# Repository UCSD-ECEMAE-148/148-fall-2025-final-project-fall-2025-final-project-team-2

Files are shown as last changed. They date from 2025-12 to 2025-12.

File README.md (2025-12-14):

<h1 align="center">Autonomous FireFighting Robot</h1>
<h3 align="center">ROS 2–Based Perception, Decision-Making, and Fire Suppression</h3>
<h4 align="center">Final Robotics Project</h4>

<br>

<div align="center">
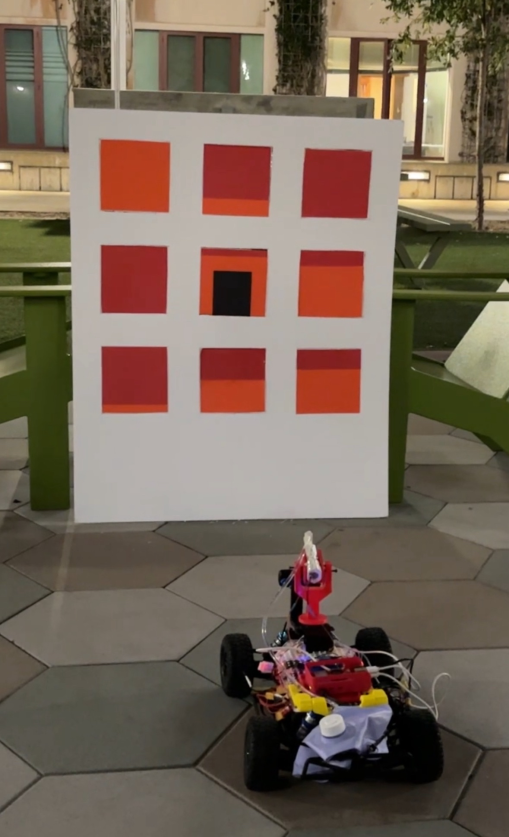
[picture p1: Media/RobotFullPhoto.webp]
  
</div>

<br>

<div align="center">
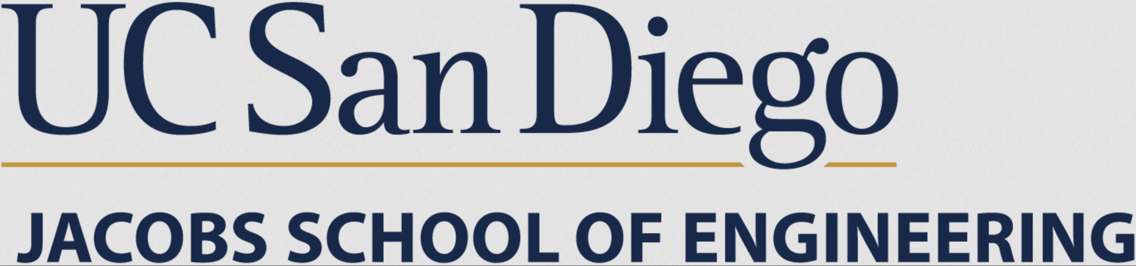
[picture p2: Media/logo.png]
  
</div>

## Table of Contents
<ol>
  <li><a href="#team-members">Team Members</a></li>
  <li><a href="#abstract">Abstract</a></li>
  <li><a href="#what-we-promised">What We Promised</a></li>
  <li><a href="#accomplishments">Accomplishments</a></li>
  <li><a href="#challenges">Challenges</a></li>
  <li><a href="#final-project-videos">Final Project Videos</a></li>
  <li><a href="#software">Software</a></li>
  <ul>
    <li><a href="#overall-architecture">Overall Architecture</a></li>
    <li><a href="#fire-perception">Fire Perception</a></li>
    <li><a href="#decision-making--task-planning">Decision-Making & Task Planning</a></li>
    <li><a href="#turret-aiming--water-cannon-control">Turret Aiming & Water Cannon Control</a></li>
    <li><a href="#navigation--localization-optional">Navigation & Localization (Optional)</a></li>
  </ul>
  <li><a href="#hardware">Hardware</a></li>
  <li><a href="#gantt-chart">Gantt Chart</a></li>
  <li><a href="#course-deliverables">Course Deliverables</a></li>
  <li><a href="#project-reproduction">Project Reproduction</a></li>
  <li><a href="#acknowledgements">Acknowledgements</a></li>
  <li><a href="#contacts">Contacts</a></li>
</ol>
<hr>

## Team Members

- **Natan Beneviste** — Mechanical Engineering
- **Vivan Tran** — Computer Engineering
- **Tanguy His** — Robotics Engineering
- **Shanil Patel** — Aerospace Enigineering

<hr>

## Abstract

The goal of this project is to develop an autonomous firefighting robot capable of detecting the locations of window fires on a mock building, estimating the severity of each fire, using a cost based algorithm to decide an optimal sequence to extinguish them efficiently, and then manipulate a relay controlled water cannon to eliminate each  window fire sequentially. 

The robot utilizes ROS2 as its foundational architecture with an OAK-D Lite camera for perception. Fire intensity is estimated from image frames using a color-based scale, more red pixels means a fire with a higher temperature and more orange pixels means a cooler fire. If a black square is present it means a person is stuck at that window location. The output of this function produces a matrix of window index, fire intensity, and person boolean (one  per window) as well as a graph for visualization. A decision-making node inputs these values into a cost based algorithm which outputs the highest value window, meaning the window that must be extinguished first. We based this algorithm on how real firefighters prioritize locations for extinguishing building fires. Finally, a turret-control node aims a servo-actuated water cannon to adjust x-axis position and the drivetrain moves to adjust y-position to aim toward the selected window in real time.  

<hr>

## What We Promised

- Detect “fire” regions (red-painted metal pieces) on a cardboard building using the OAK-D Lite camera.
- Estimate a fire intensity for each window.
- Publish a structured list of targets to ROS2.
- Compute the next best target using a custom score function.
- Aim a single-servo turret and acutated the drivetrain toward the selected window and trigger suppression.

<hr>

## Accomplishments
- **Fire Perception Node**
  - Implemented ROI-based window extraction.
  - Implemented red-orange-intensity estimation.
  - Can detect the presence of a person ( based on a non red/orange color that's in the window).
  - Published a fire-node list containing window IDs, temperatures, and neighbor influence values.
- **Decision-Making Node**
  - Implemented graph-based target representation.
  - Implemented next-target selection using a custom score formulation (distance + intensity + neighbor effects + presence of a person at the window).
- **Turret Control Node**
  - Implemented camera-based aiming for a 1-DOF turret.
  - Implemented drivetrain control for y-position movement  
  - Implemented servo PWM output with limits.

<hr>

## Challenges

- **Robust perception under lighting variation**
  - Red detection is sensitive to illumination;
- **System integration**
  - Ensuring consistent message timing and stable TF/frame assumptions across nodes.
  - Having the Brain Node sequentially run the other nodes 
- **Power and reliability**
  - Separating high-current actuator power (pump/motors) from logic power and filtering noise are critical for stable operation.
<hr>

## Final Project Videos

Final project demonstration: https://youtube.com/shorts/yiU66X_UAJ0
<hr>

## Software

### Overall Architecture

This project was developed in ROS2 using a modular pipeline that cleanly separates perception, decision-making, and hardware. Each stage runs as an independent ROS2 node and is communicated exclusively through topics allowing the system to be sequential.

The system will execute and repeat this sequence:

see → decide → servo → drivetrain → fire

---

## ROS 2 Node-Level Architecture

<div align="center">
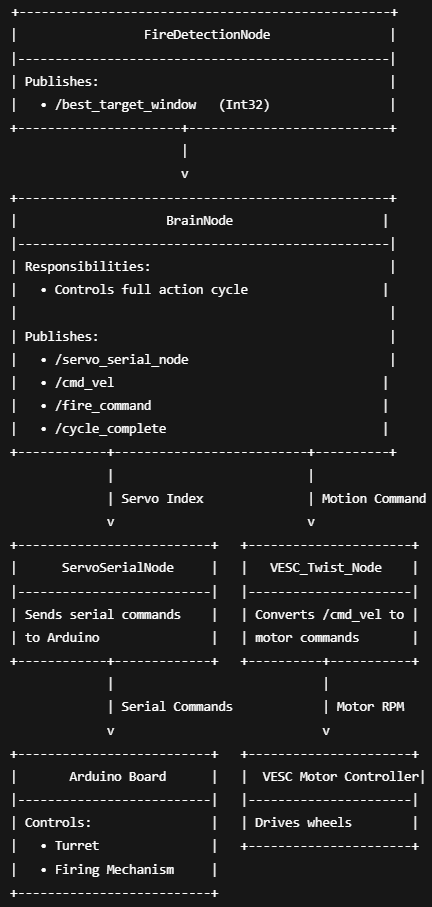
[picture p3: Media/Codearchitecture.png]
  
</div>

---

### HSV Window Labeling
<div align="center">
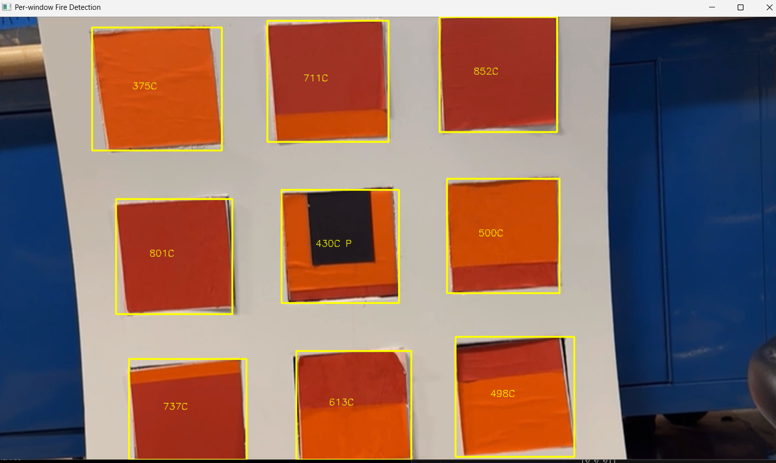
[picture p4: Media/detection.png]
  
</div>
Heat is determined through the amount of red and orange pixels. More red indicates hotter temperate and more orange indicates cooler temperatures. There is a black box that will show there is a person present in the window. The mock building made of cardboard will have these variables present and the HSV Window Labeling will output those live variables to a matrix with window id, fire intensity, neighbors fire intensity, person present boolean.

---

**ROI-based window extraction**

- A calibration step defines fixed window bounding boxes (ROIs).
- Each incoming frame is cropped into per-window patches.
- Each patch is resized and normalized.

---

**Intensity estimation**

**Baseline (color-based):**

- Convert ROI to HSV or La for improved robustness to lighting changes.
- Compute a red/orange intensity score based on hue and saturation thresholds.
- Map this score to a normalized temperature or fire intensity index.

---

**Output message**

The HSV Window Labeling library publishes a structured list of detected fire windows:

- window ID – lists windows in matrix order
- temperature / intensity – determined through the amount of orange and red (outputted as a 3x3 matrix correlated with the window ID)
- Boolean Person matrix – 3x3 matrix, 1 indicated that there is a person, 0 otherwise

---

### Decision-Making & Task Planning

The decision-making library will input the matrix form the HSW Window Labeling, applying the formula (indicated below) and then outputting the window with the highest cost, needing to be extinguished first. 

At each iteration, the function selects the next window to extinguish by minimizing a custom cost:

- balance between:
  - travel cost (distance/time),
  - fire urgency (temperature),
  - cluster effects (neighbor influence),
  - predicted growth over time,
  - presence or not of a person

This is the equation:

cost = w1 · travel_cost
     + w2 · fire_intensity
     + w3 · neighbor_influence
     + w4 · predicted_growth
     + w5 · safety_penalty

---

### Fire_Dection_Node

The Fire Detection Node is responsible for converting raw camera images into a structured, decision-ready representation of the fire activity across the building. It serves as the interface between perception and decision-making, encapsulating fire detection, temperature estimation, reasoning, and debugging visualization.

This node performs three tightly integrated functions:

- Camera Input Processing
- HSV window labeling & Temperature Estimation
- Target Selection & Debug Matrix Generation

The output topics:

- Best_window → the window id of the current highest priority window
- Debug information

<div align="center">
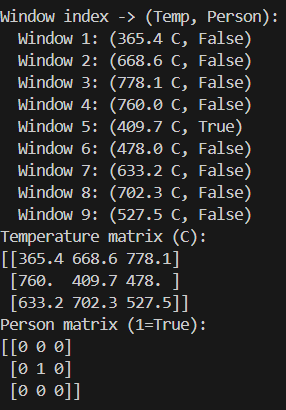
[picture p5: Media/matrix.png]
  
</div>
---

## Servo Node

Our turret has 1 servo. The camera is mounted ~5–6 cm in front of the turret base, fixed to the chassis.

### System Operation and Communication

The servo’s horizontal motion is controlled using the Arduino’s built-in **Servo library**, which sets the servo angle by outputting the appropriate **PWM signal**.

To activate the water cannon, the Arduino sends a **digital control signal** to a **relay**, which acts like an electronic switch—when triggered, it allows power to flow to the water cannon so it can fire.

The **Raspberry Pi** and **Arduino** communicate using **serial (UART) communication**. In this setup, the Raspberry Pi sends commands (such as 0–8 the windows label or “fire”) over the serial connection, and the Arduino interprets those commands and performs the real-time hardware actions (servo positioning and relay switching).

This division of roles keeps the Raspberry Pi protected from motor/relay electrical noise while allowing the Arduino to handle the precise timing needed for servo control and reliable firing.

**Summary:**

Subscribe to:
- `/fire_command` (Bool)

Interacts with:
- Arduino via `/dev/serial/...` (USB)

Sends:
- Servo angle commands (window index) to ardunio 
- FIRE command to arduino 

<hr>

### VESC Node

The **VESC node** acts as the main **motor driver interface** in our ROS2 system. It serves as the software bridge between ROS and the physical drivetrain hardware controlled by the VESC.

## Command Input (Subscribing to Motion Topics)

The best_window topic determines the target row, which requires movement either forward, backward, or idle. The VESC node listens to those motion commands published by `/cmd_vel`.

## Command Translation (ROS → VESC Control)

Once a command is received, the VESC node converts the ROS message into the low-level control signals that the VESC understands. This is what allows high-level ROS navigation or control logic to directly drive the motor without needing to handle hardware-level details.

## Feedback Output (State and Odometry Publishing)

In addition to sending commands, the VESC node publishes feedback data back into ROS such as motor speed, voltage, current draw, and/or **odometry**. This feedback helps the system confirm the drivetrain is responding correctly and track how far the robot has moved.

## Why This Matters

By separating motion commands from hardware control, the VESC node makes the drivetrain easier to control and debug. Other ROS nodes can focus on decision-making while the VESC node handles reliable motor execution and feedback. Therefore handles the forward and backward movement of the car needed for aiming the row.

### Brain Node

The Brain Node is the central decision-making and coordination node of the system. It acts as the bridge between fire perception and the hardware, ensuring that all actions occur in the correct order and without conflict.

Rather than continuously commanding hardware, the Brain Node operates as a finite state machine (FSM) that executes a single fire-suppression cycle at a time.

Its responsibilities are to:
- Receive the best_window_id
- Coordinate turret aiming, base motion, and firing system
- Signal when the cycle is complete so perception may resume

Subscribe topic:
- `/best_target_window` (Int32)

Publishes topics:
- `/servo_serial_node` (Int32)
- `/cmd_vel` (Twist)
- `/fire_command` (Bool)
- `/cycle_complete` (Bool)

---

### Internal State Machine

The Brain Node is implemented as a finite state machine to guarantee correct sequencing and prevent unsafe behavior.

**State Definitions**

- IDLE – Waiting for a valid fire target
- AIM_TURRET – Rotate turret toward target window
- MOVE_BASE – Move robot to align with target row
- FIRE – Activate water cannon
- RESET – Stop motion and unlock next cycle

---

**Execution Logic**

1. **Target Acquisition (IDLE)**  
   The Brain Node waits for `/best_target_window`.  
   Once received, it:
   - Validates the window index
   - Stores temperature and metadata
   - Locks the system to prevent new targets

2. **Turret Aiming (AIM_TURRET)**  
   - Converts the window index into a target column  
   - Publishes `/servo_serial_node` with the desired turret position  
   - Waits a fixed settling time to allow servo stabilization  
   - Prevents firing while the turret is still moving

3. **Base Alignment (MOVE_BASE)**  
   - Converts the window index into a target row  
   - Publishes `/cmd_vel` to move the robot forward or backward  
   - Uses time-based or distance-based motion control  
   - Stops motion once alignment is achieved

4. **Fire Command (FIRE)**  
   - Publishes `/fire_command = true`  
   - Holds the command long enough to ensure actuation  
   - Immediately resets `/fire_command` to false  

5. **Reset & Unlock (RESET)**  
   - Publishes `/cycle_complete = true`  
   - Clears internal state variables  
   - Returns to IDLE  

At this point, the perception node is allowed to process the next frame.

<hr>

## Hardware

**Compute**
- Raspberry Pi 5
- Arduino Leondardo Micro 
- MicroSD storage

**Sensors**
- OAK-D Lite RGB-D camera
**Actuation**
- 1x servo motor
- water pump / solenoid valve
- chassis drivetrain (VESC + motor)

**Power**
- 4S LiPo battery
- Dedicated DC-DC converters (logic 5V separated from high-current actuators)
- anti-spark voltage monitoring
  <div align="center">
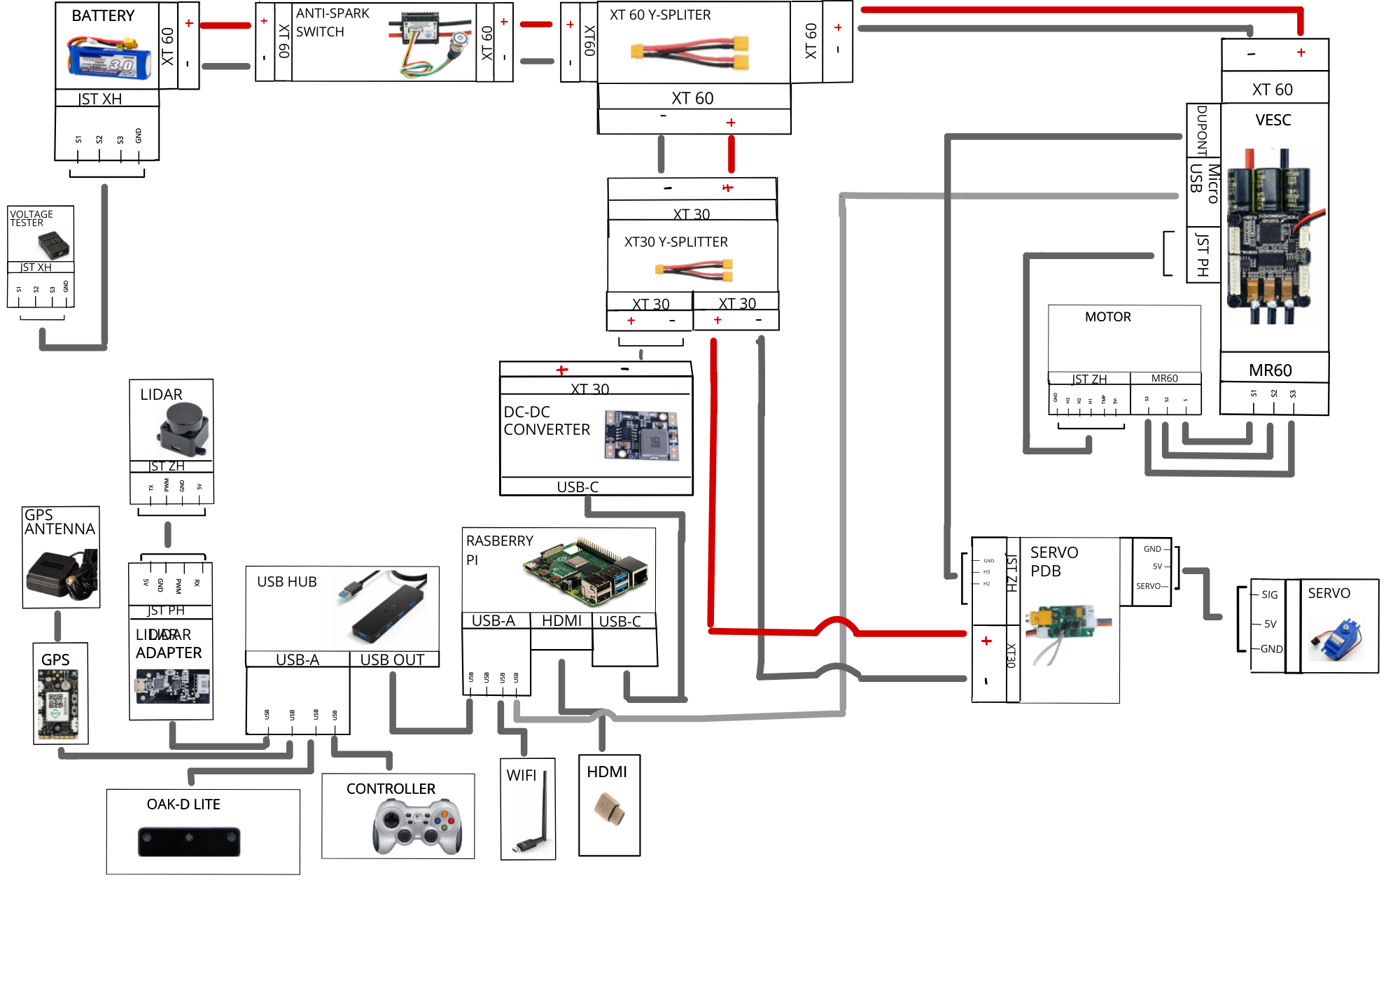
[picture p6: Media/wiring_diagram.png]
  
</div>

**Mechanical**
- Cardboard mock building with painted metal “windows”
- 3D-printed base plate
  <div align="center">
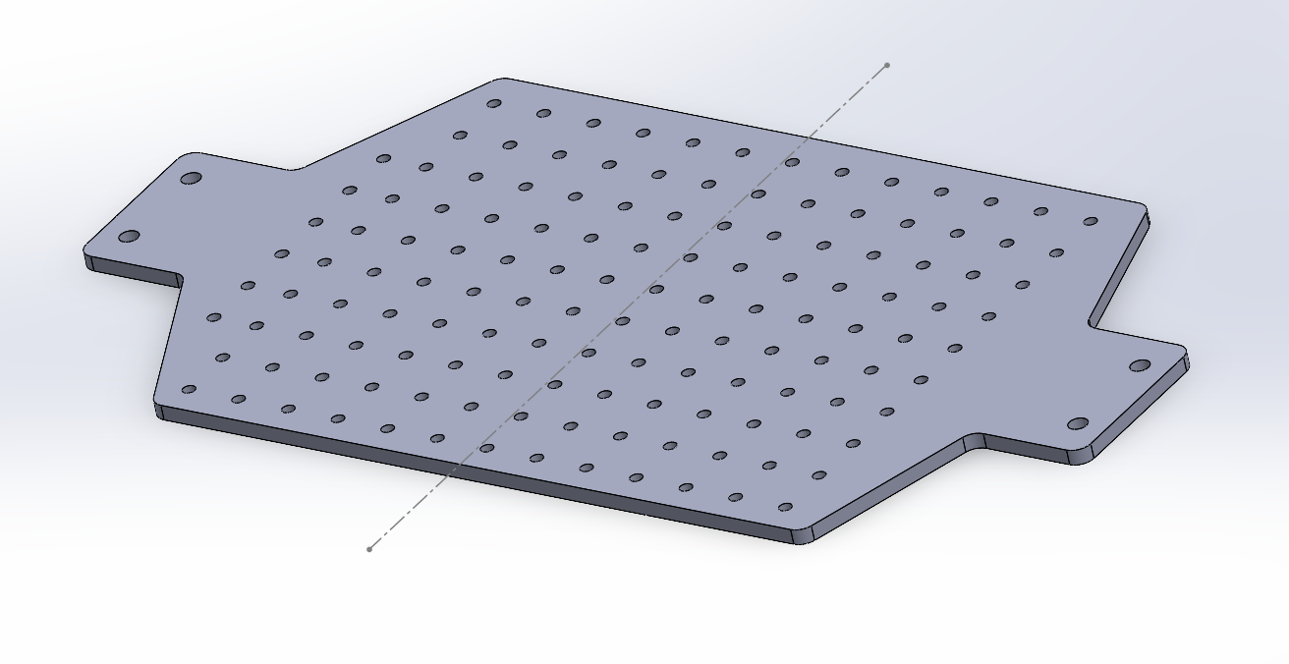
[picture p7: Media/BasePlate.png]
  
</div>
- 3D-printed mounts for camera and turret
<div align="center">
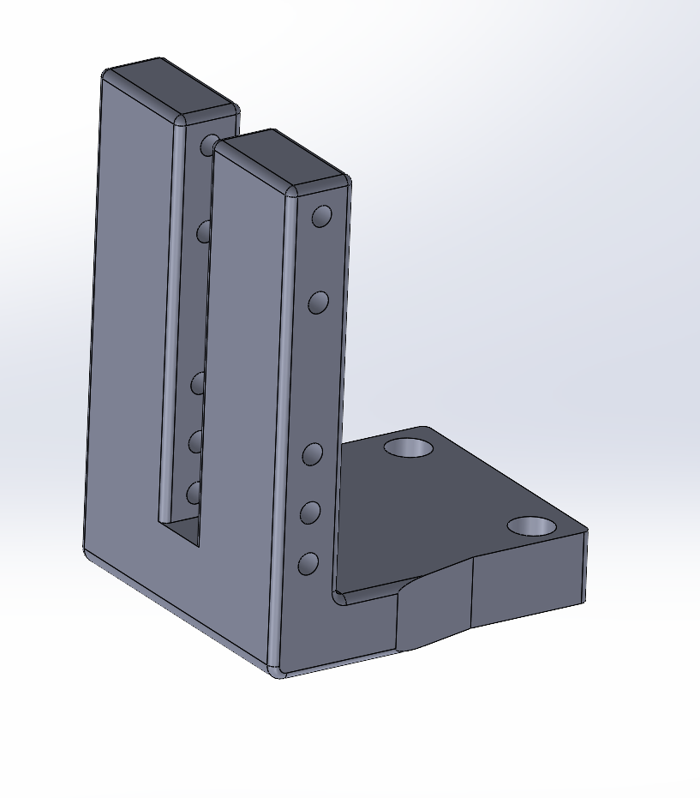
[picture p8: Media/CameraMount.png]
  
</div>
<div align="left">
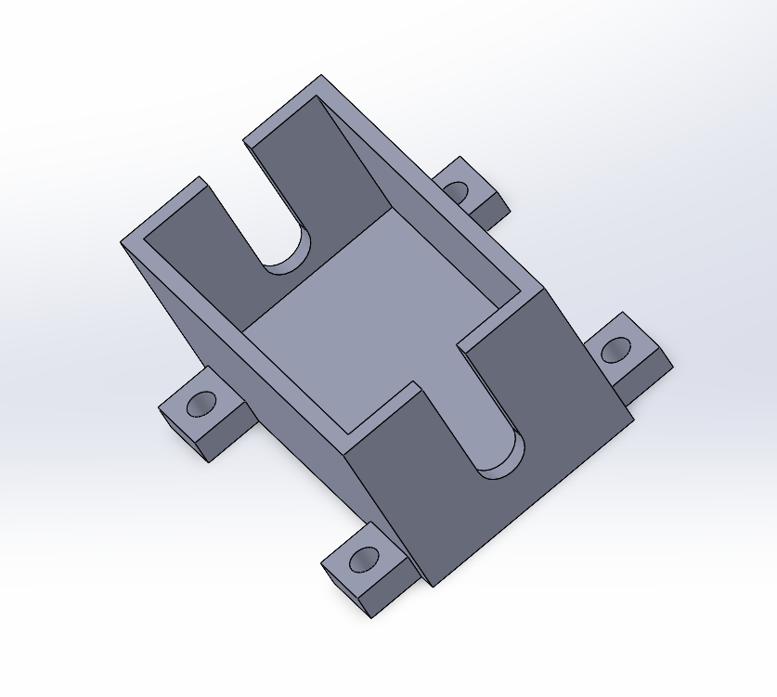
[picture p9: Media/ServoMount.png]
  
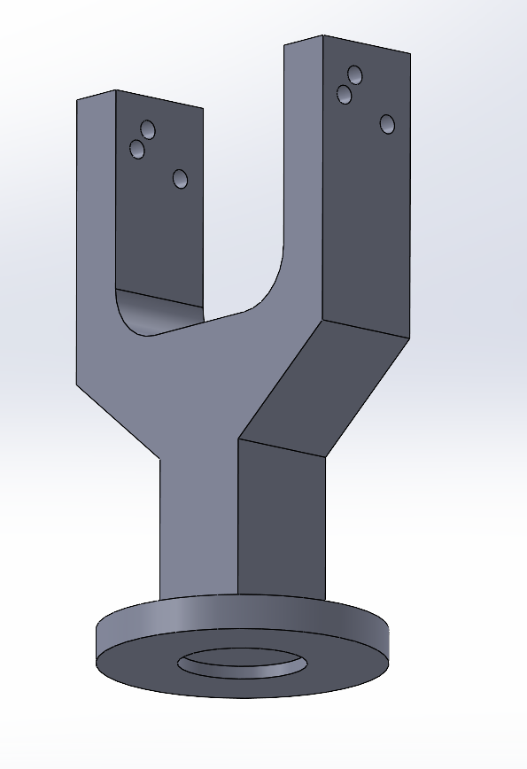
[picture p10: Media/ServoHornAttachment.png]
  
</div>
<hr>

## Water Cannon Design Choice

We chose to use a water cannon from a electronic squirt gun because it was a budget-friendly option that already included everything we needed to perform the task, such as:
- a strong pump  
- a built-in water tank  
- a compact design for easy mobility  

To protect the electronics, we kept the water tank in the trunk of the car so any leaks or spills wouldn’t risk shorting components.

## Mounting and Rotation Mechanism

We used a simple 3D-printed design to hold the water cannon securely, then the servo was mounted in a grove on the underside of the water cannon bracket to allow for it    x-position movement.

The baseplate layout was planned to leave:
- enough space on top for the servo mount  
- room for the targeting mechanism

<div align="left">
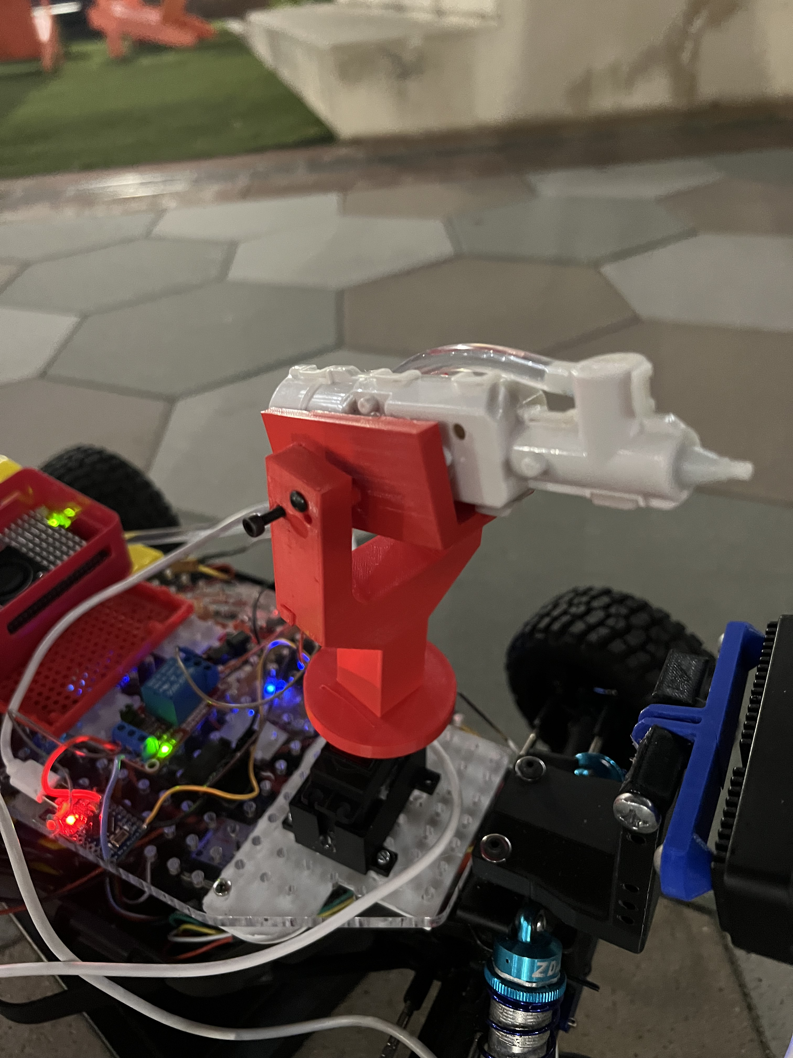
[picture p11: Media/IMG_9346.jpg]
  

## Steering Lock for Accuracy

To prevent the cannon from drifting off-target, we detached the car’s steering servo and locked it in place. This ensured there were no unintended direction changes while firing.

## Gantt Chart

 <div align="center">
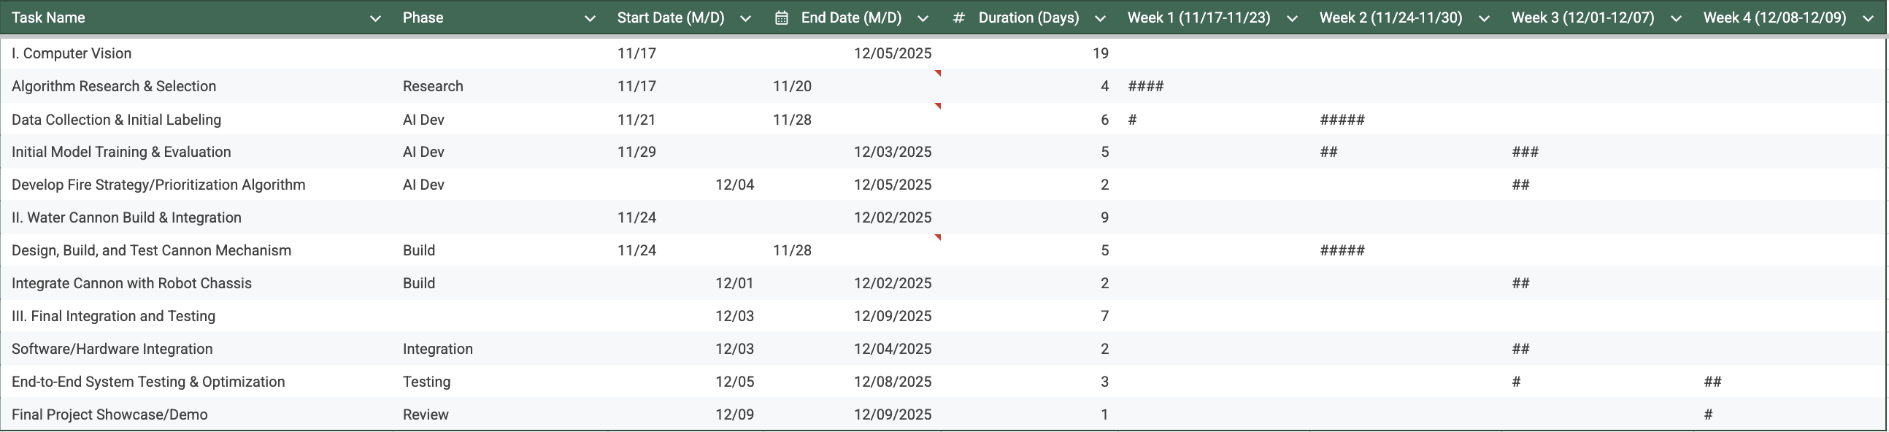
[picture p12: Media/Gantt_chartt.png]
  
</div>
<hr>

## Course Deliverables

* Functionnal car: https://youtu.be/cYO1r23sewk
* Deep learning laps: https://youtu.be/hFGpkKaZCqE
* GPS laps : https://youtu.be/9ZRp8OY7T6o
* Opencv lane following: https://youtu.be/XaypVPjqVfU
<hr>

## Project Reproduction
To reproduce this project:

<ol>
  <li>Install ROS2 and create a workspace.</li>
  <li>Install DepthAI ROS driver (OAK-D Lite support).</li>
  <li>Clone this repository:
<pre>
cd ~/ros2_ws/src
git clone --recurse-submodules https://github.com/YOUR_ORG/YOUR_REPO.git
</pre>
  </li>
  <li>Build:
<pre>
cd ~/ros2_ws
colcon build
source install/setup.bash
</pre>
  </li>
  <li>Launch perception:
<pre>
ros2 launch firefighter_perception perception.launch.py
</pre>
  </li>
  <li>Launch decision:
<pre>
ros2 launch firefighter_decision decision.launch.py
</pre>
  </li>
  <li>Launch turret control:
<pre>
ros2 launch firefighter_turret turret.launch.py
</pre>
  </li>
</ol>

<hr>

## Acknowledgements

Special thanks to Professor Jack Silberman and TA's Winston Chou and Aryan Palaskar for delivering the course !

**References**
- ROS2: https://docs.ros.org/
- DepthAI ROS Driver: https://github.com/luxonis/depthai-ros

<hr>

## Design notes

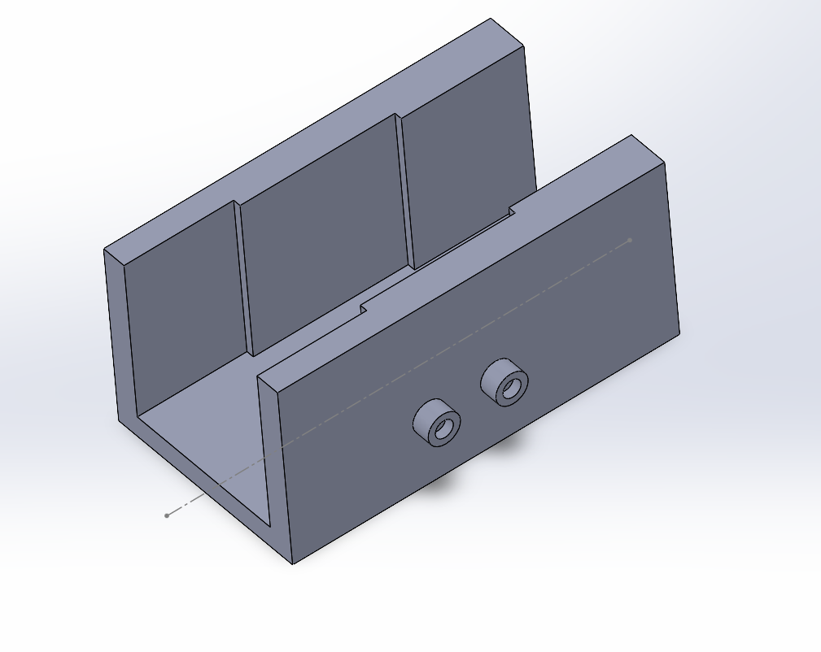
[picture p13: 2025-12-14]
Media/WaterGunMount.png

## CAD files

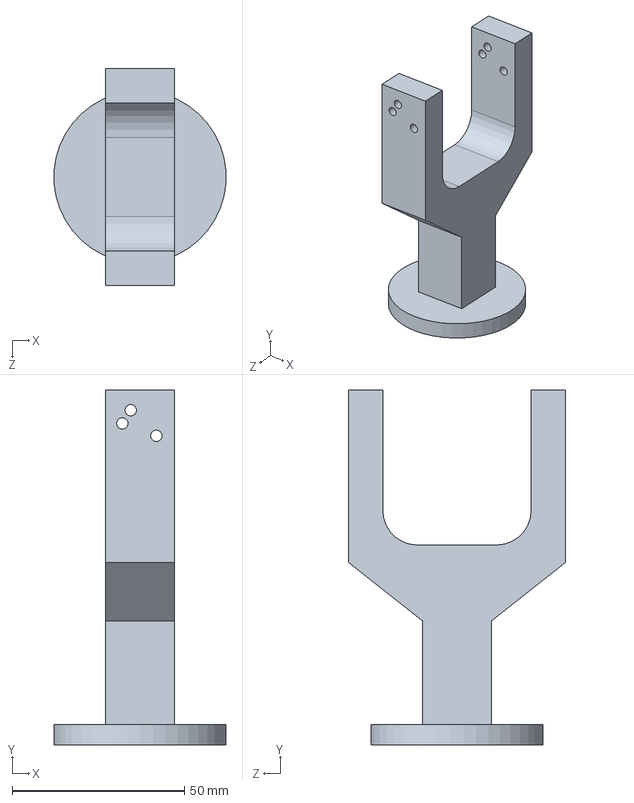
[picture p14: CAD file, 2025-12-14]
Media/WatergunturretV1.SLDPRT
49.9 x 103.0 x 63.0 mm

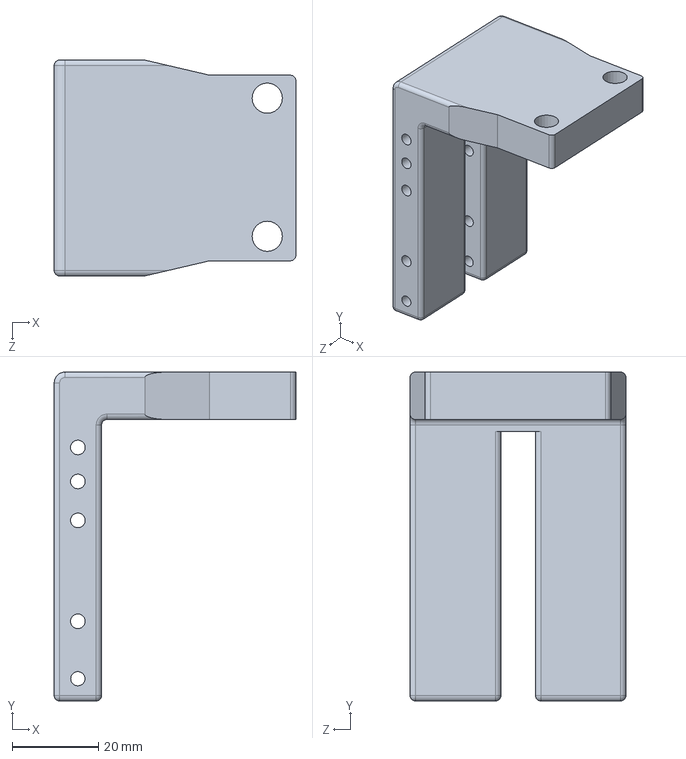
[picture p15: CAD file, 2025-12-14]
Media/camera mount.SLDPRT
56.0 x 76.2 x 50.0 mm

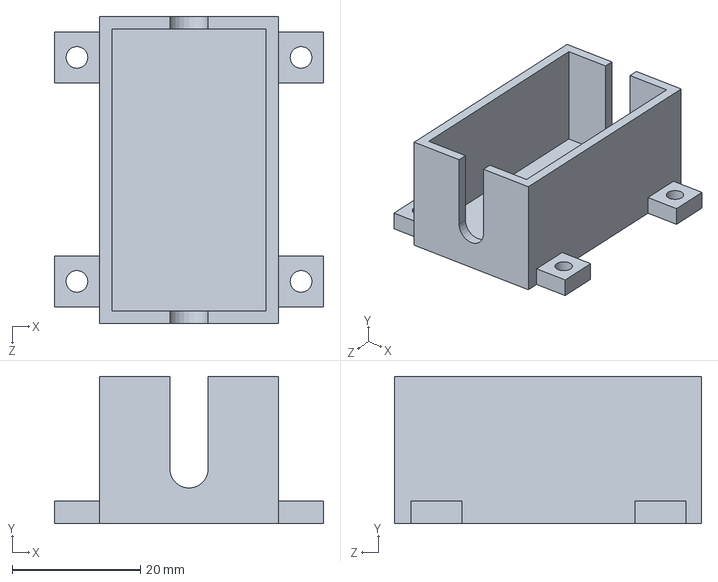
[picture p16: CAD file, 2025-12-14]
Media/ServoMount.SLDPRT
42.0 x 23.0 x 48.0 mm

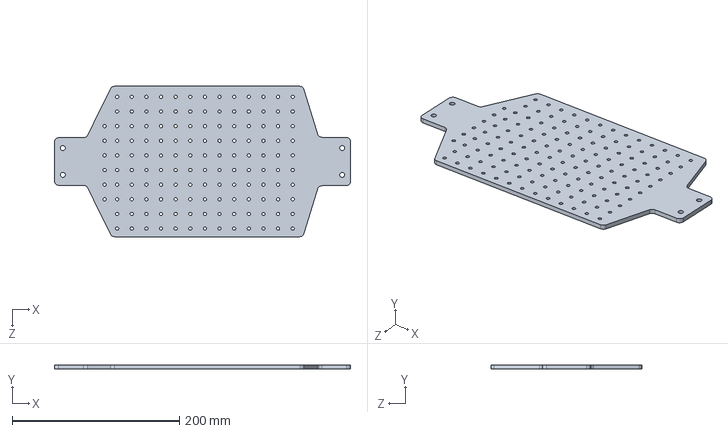
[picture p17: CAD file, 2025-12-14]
Media/MAE148newbaseplate.SLDPRT
354.0 x 5.00 x 180.0 mm

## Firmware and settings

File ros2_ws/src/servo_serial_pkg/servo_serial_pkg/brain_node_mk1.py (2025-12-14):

#!/usr/bin/env python3
import rclpy
from rclpy.node import Node

from std_msgs.msg import Int32, Bool
from geometry_msgs.msg import Twist


class BrainNode(Node):
    """
    Sequence (one cycle at a time):

      1) FireDetectionNode publishes /best_target_window (0..8).
      2) servo_serial_node immediately sends that index to Arduino (servo moves).
      3) Brain waits SERVO_SETTLE_SEC.
      4) Brain publishes /cmd_vel to move the base (vesc_twist_node).
      5) Brain waits VESC_MOVE_SEC.
      6) Brain publishes /cmd_vel stop + /fire_command = True.
      7) Marks sequence as done -> next /best_target_window can start a new cycle.
    """

    SERVO_SETTLE_SEC = 0.7   # time for servo to finish turning
    VESC_MOVE_SEC = 1.0      # time for base/VESC to move

    def __init__(self):
        super().__init__('brain_node')

        self.current_target_idx = None

        # Are we currently in the middle of a sequence?
        self.sequence_active = False

        # Publish directly to existing VESC twist topic
        self.cmd_pub = self.create_publisher(Twist, 'cmd_vel', 10)

        # Publish fire trigger (servo_serial_node -> Arduino)
        self.fire_pub = self.create_publisher(Bool, 'fire_command', 10)

        # Subscribe to best target window from fire_detection_node
        self.best_sub = self.create_subscription(
            Int32,
            'best_target_window',
            self.best_target_callback,
            10
        )

        # Timers for sequencing
        self.servo_timer = None
        self.vesc_timer = None

        self.get_logger().info("BrainNode started: listening to /best_target_window")

    # -------------------- Callbacks --------------------

    def best_target_callback(self, msg: Int32):
        """
        Called whenever FireDetectionNode picks a best window.
        If no sequence is running, start a new sequence.
        If a sequence is already running, ignore this message.
        """
        idx = int(msg.data)
        self.get_logger().info(f"New best_target_window = {idx}")

        if self.sequence_active:
            # Prevent timers from constantly restarting
            self.get_logger().info("Sequence already active; ignoring new best_target_window.")
            return

        self.sequence_active = True
        self.current_target_idx = idx

        # Start servo settle timer
        self.servo_timer = self.create_timer(
            self.SERVO_SETTLE_SEC,
            self._on_servo_settled
        )
        self.get_logger().info("Started servo settle timer.")

    def _on_servo_settled(self):
        """Called after we assume the servo has finished turning."""
        # One-shot timer -> cancel it
        if self.servo_timer is not None:
            self.servo_timer.cancel()
            self.servo_timer = None

        if self.current_target_idx is None:
            self.get_logger().warn("Servo settled but no current target index.")
            self.sequence_active = False
            return

        # Convert 0..8 window index into row 0..2
        row = int(self.current_target_idx) // 3
        self.get_logger().info(f"Row for base movement = {row}")

        # Map row -> linear.x speed (tune these for your robot!)
        if row == 0:
            speed = 0.5    # forward
        elif row == 1:
            speed = 0.0    # stay
        elif row == 2:
            speed = -0.5   # backward
        else:
            self.get_logger().warn(f"Unknown row {row}, stopping.")
            speed = 0.0

        twist = Twist()
        twist.linear.x = float(speed)
        twist.angular.z = 0.0

        self.cmd_pub.publish(twist)
        self.get_logger().info(f"Published /cmd_vel linear.x = {speed}")

        # Start timer for VESC/base movement
        self.vesc_timer = self.create_timer(
            self.VESC_MOVE_SEC,
            self._on_vesc_moved
        )
        self.get_logger().info("Started VESC move timer.")

    def _on_vesc_moved(self):
        """Called after we assume the base has repositioned under the target."""
        # One-shot timer -> cancel
        if self.vesc_timer is not None:
            self.vesc_timer.cancel()
            self.vesc_timer = None

        # 1) Stop the base
        stop_twist = Twist()
        stop_twist.linear.x = 0.0
        stop_twist.angular.z = 0.0
        self.cmd_pub.publish(stop_twist)
        self.get_logger().info("Published /cmd_vel stop (0.0)")

        # 2) Fire once
        fire_msg = Bool()
        fire_msg.data = True
        self.fire_pub.publish(fire_msg)
        self.get_logger().info("Published fire_command = True")

        # 3) Mark sequence as done so we can react to the next best_target_window
        self.sequence_active = False
        self.get_logger().info("Sequence complete; ready for next target.")

    # -------------------- Helpers --------------------

    def destroy_node(self):
        # Cleanly cancel timers on shutdown
        if self.servo_timer is not None:
            self.servo_timer.cancel()
        if self.vesc_timer is not None:
            self.vesc_timer.cancel()
        super().destroy_node()


def main(args=None):
    rclpy.init(args=args)
    node = BrainNode()
    try:
        rclpy.spin(node)
    finally:
        node.destroy_node()
        rclpy.shutdown()


if __name__ == '__main__':
    main()

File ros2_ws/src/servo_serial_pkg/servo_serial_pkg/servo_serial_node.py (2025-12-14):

#!/usr/bin/env python3
import rclpy
from rclpy.node import Node
from std_msgs.msg import Int32, Bool

import serial
import time


class WindowSerialNode(Node):
    def __init__(self):
        super().__init__('window_serial_node')

        # 🔥 CHANGE THIS TO YOUR STABLE PATH
        self.port =  "/dev/ttyACM1"
       # self.port = "/dev/serial/by-id/usb-Arduino_LLC_Arduino_Leonardo-if00"


        self.baud = 115200
        self.ser = None
        self.connected = False
        self.reconnect_timer = None

        # ROS Subscribers
        self.best_sub = self.create_subscription(
            Int32, 'best_target_window', self.on_best_window, 10
        )
        self.fire_sub = self.create_subscription(
            Bool, 'fire_command', self.on_fire_command, 10
        )

        self.get_logger().info(
            f"WindowSerialNode starting... opening serial: {self.port} @ {self.baud}"
        )

        # Try initial connect
        self.try_open_serial()

    # -------------------------------------------------------
    # SERIAL CONNECTION MANAGEMENT
    # -------------------------------------------------------

    def try_open_serial(self):
        """Attempt to open serial port. If fails, schedule reconnect."""
        if self.connected:
            return

        try:
            self.get_logger().info(
                f"Opening serial port {self.port} at {self.baud}..."
            )
            self.ser = serial.Serial(self.port, self.baud, timeout=1)

            # Reset Leonardo cleanly
            self.ser.dtr = False
            time.sleep(0.1)
            self.ser.dtr = True

            time.sleep(2.0)  # allow Leonardo to reboot

            self.connected = True
            self.get_logger().info(
                "Serial connected — Arduino ready."
            )

            # Stop reconnect timer if running
            if self.reconnect_timer is not None:
                self.reconnect_timer.cancel()
                self.reconnect_timer = None

        except Exception as e:
            self.connected = False
            self.get_logger().warn(f"Serial open failed: {e}")

            # Start reconnect attempts
            if self.reconnect_timer is None:
                self.reconnect_timer = self.create_timer(1.0, self.on_reconnect_timer)

    def on_reconnect_timer(self):
        """Keep trying to reconnect until successful."""
        if not self.connected:
            self.try_open_serial()
        else:
            if self.reconnect_timer:
                self.reconnect_timer.cancel()
                self.reconnect_timer = None

    def write_line(self, line: str, is_fire: bool = False):
        """Safely write to serial and auto-reconnect on disconnect."""
        if not self.connected or self.ser is None:
            return

        try:
            data = (line + "\n").encode("utf-8")
            self.ser.write(data)
            self.ser.flush()

            if is_fire:
                self.get_logger().info("Sent to Arduino: FIRE")
            else:
                self.get_logger().info(f"Sent to Arduino: {line}")

        except (serial.SerialException, OSError) as e:
            # USB disconnect → Errno 5 → Arduino rebooted → reconnect
            if is_fire:
                self.get_logger().error(f"Error writing FIRE: {e}")
            else:
                self.get_logger().error(f"Error writing: {e}")

            self.connected = False

            try:
                self.ser.close()
            except Exception:
                pass
            self.ser = None

            # Begin reconnect loop
            if self.reconnect_timer is None:
                self.reconnect_timer = self.create_timer(1.0, self.on_reconnect_timer)

    # -------------------------------------------------------
    # ROS CALLBACKS
    # -------------------------------------------------------

    def on_best_window(self, msg: Int32):
        self.write_line(str(msg.data))

    def on_fire_command(self, msg: Bool):
        if msg.data:
            self.write_line("FIRE", is_fire=True)

    # -------------------------------------------------------
    # CLEANUP
    # -------------------------------------------------------

    def destroy_node(self):
        if self.reconnect_timer:
            self.reconnect_timer.cancel()
        if self.ser:
            try:
                self.ser.close()
            except Exception:
                pass

        super().destroy_node()


def main(args=None):
    rclpy.init(args=args)
    node = WindowSerialNode()

    try:
        rclpy.spin(node)
    except KeyboardInterrupt:
        pass
    finally:
        node.destroy_node()
        rclpy.shutdown()


if __name__ == "__main__":
    main()
